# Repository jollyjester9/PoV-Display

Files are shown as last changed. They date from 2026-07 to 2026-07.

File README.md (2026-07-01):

<br/>
<div align="left">

<h2 align="left">Peristance of Vision Display</h2>
<p align="left">
ESP32 powered PoV Display

</p>
</div>

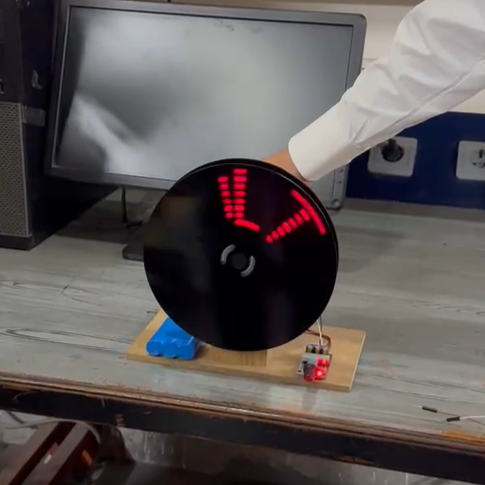
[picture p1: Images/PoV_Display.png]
PoV Display


## About The Project

This project aims to Create a rotating word display using an array of eight LEDs Powered by an ESP32 microcontroller.

## Components/ Parts List

### Off the shelf:
- ESP32 Dev Board
- RS-775 Motor
- PWM Dimmer
- 11.1 Volt Lithium Battery
- 4.8 Volt Lithium Battery
- M4*12 screws x 4
- M3*4 screws x 4
- SS41F Hall Effect Sensor
- 5mm LEDs (Red) x 8
- 330 ohm resistor x 8
- 10 kilo ohm resistor x 1

### Custom:
- Motor Mount
- Motor Adapter
- ESP Mount
- Rotating Disk
- Stationary Disk

## Built With

- [Arduino IDE](https://www.arduino.cc/en/software/)
- [Fusion](https://www.autodesk.com/products/fusion-360/overview)

## Hardware assembly

The assembly consists of two disks, one stationary and one rotating. Two Neodymium magnets are placed on the stationary disk, 144 degrees apart, which acts as the trigger angle and sets the output window size. The magnets are placed with opposite poles facing outward. A bipolar hall effect latch is used to detect the alternating magnetic field and enable/ disable the LED array as well as calculate disk RPM.

### Stationary Disk:

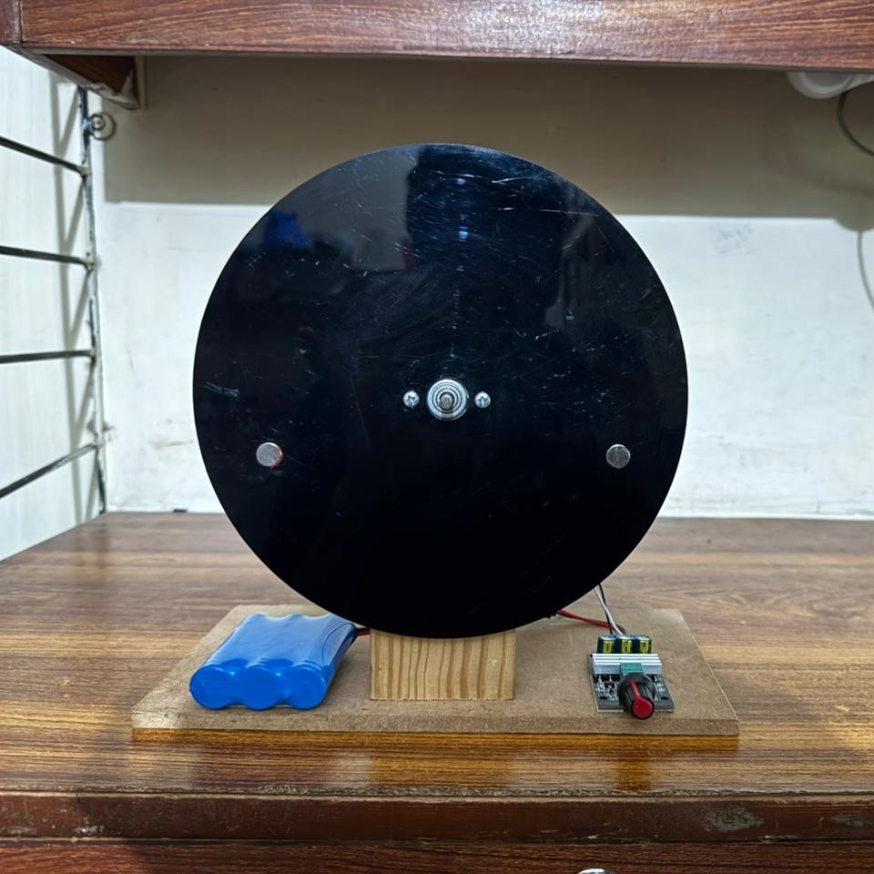
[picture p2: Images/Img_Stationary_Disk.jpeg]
Stationary_Disk


### Rotating Disk:

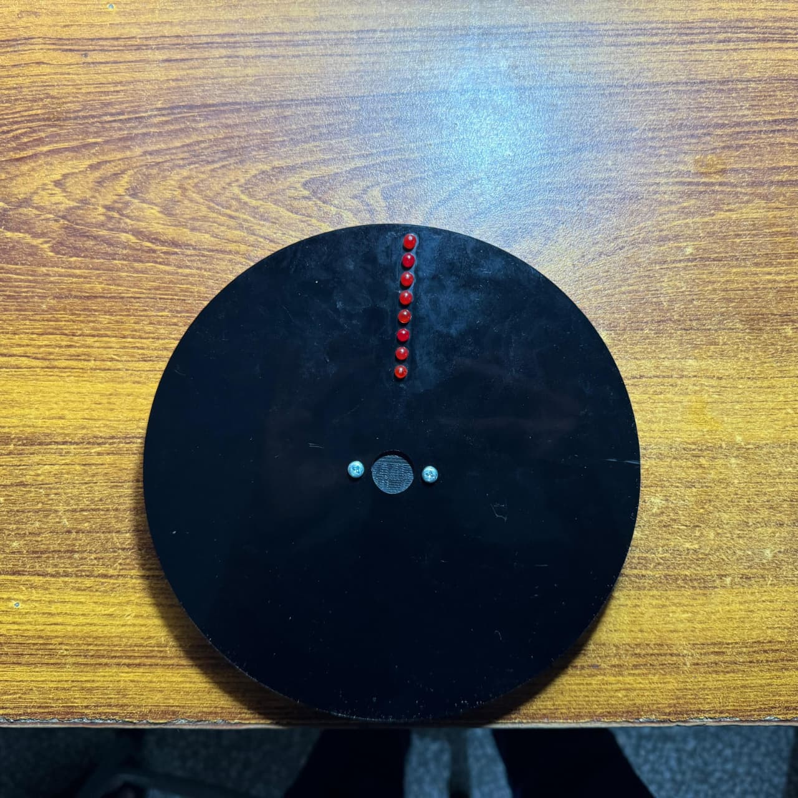
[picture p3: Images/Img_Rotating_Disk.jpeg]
Rotating_Disk


### Rotating Disk (Backside):

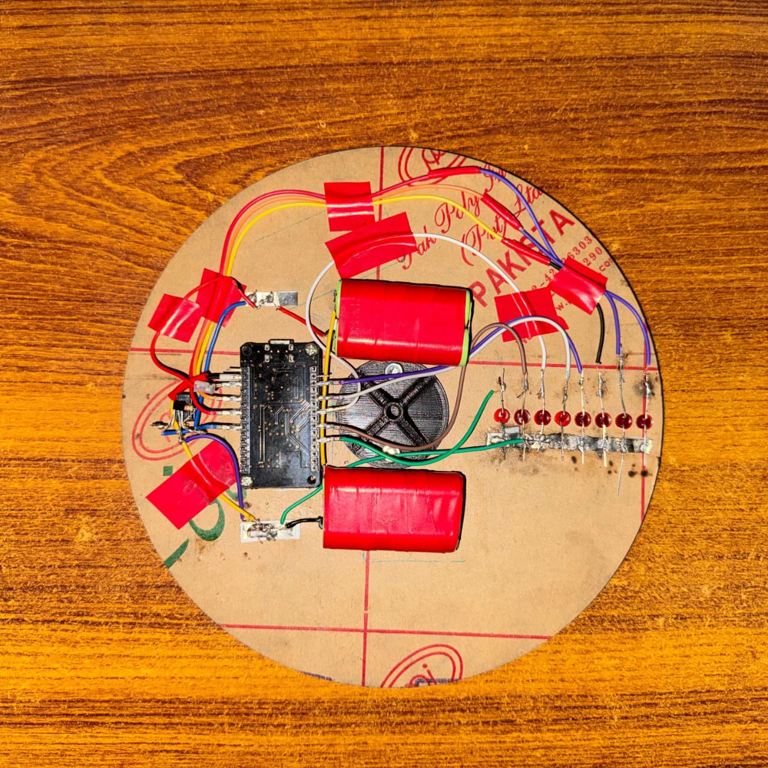
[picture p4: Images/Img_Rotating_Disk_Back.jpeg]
Rotating_Disk


The rotating disk is divided into 60 columns which gives, the number of columns available for display are:

$${144 \over 360} \times 60 = 24$$

The Rotating disk is spun using an RS-775 motor, a PWM dimmer is used to control motor RPM;
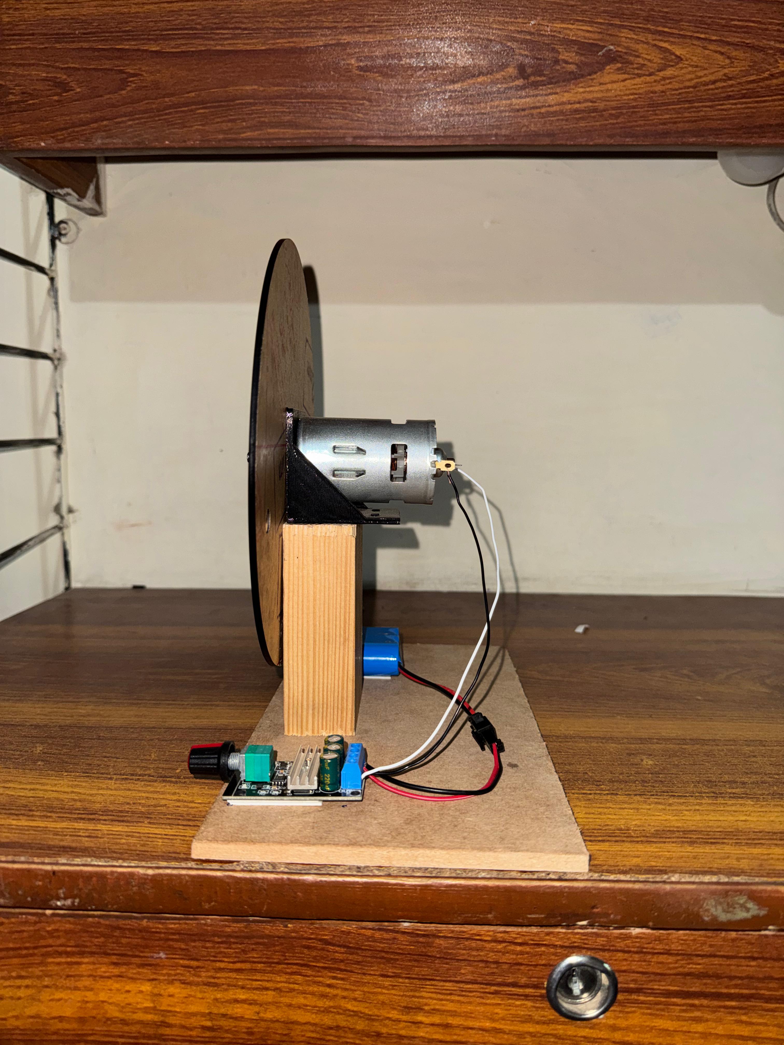
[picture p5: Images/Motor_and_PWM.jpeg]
Motor


## Code overview

To change display resolution, edit:
```sh
   #define NUM_COLS  23
   ```   
To change window size, edit (note: this will require changing magnet spacing on the stationary disk)
```sh
   #define ACTIVE_FRAC 0.4f
   ```

In [Encoding.xlsx](https://github.com/jollyjester9/PoV-Display/blob/main/Encoding.xlsx), each character takes 5 columns so by default, a four character expression is supported with 1 column acting as spacing between characters.

The characters are stored as hex values, for example, 'V' is stored as;
```sh
   const uint8_t CHAR_V[5] = {0x07, 0x38, 0xC0, 0x38, 0x07};
   ```

The code iterates through all 24 columns, updates the current columns and outputs the corresponding 8 bit value to the LEDs

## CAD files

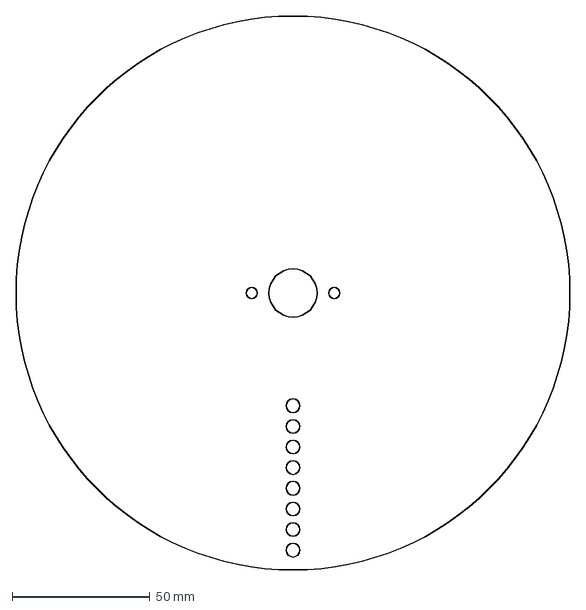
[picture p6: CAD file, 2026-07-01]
Parts/Rotating_Disk.dxf
201.4 x 201.4 mm

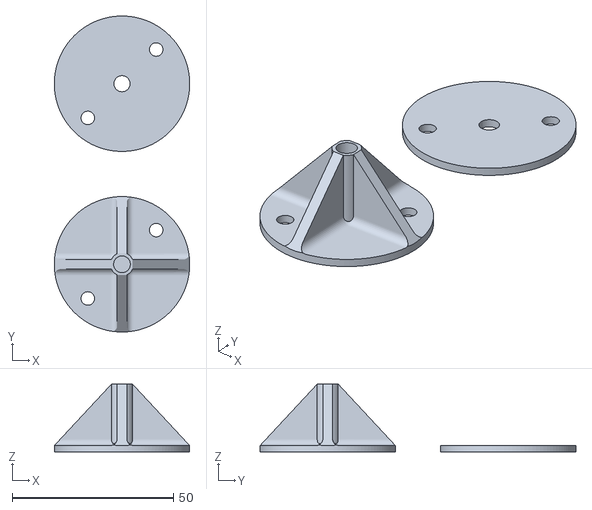
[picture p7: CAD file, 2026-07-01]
Parts/Motor_Adapter_v1.2.stl
42.0 x 98.0 x 21.0

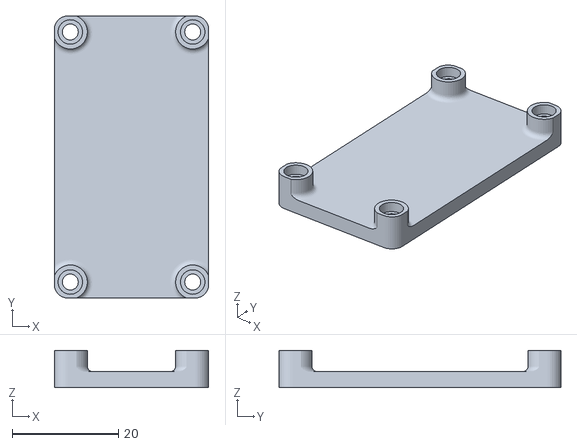
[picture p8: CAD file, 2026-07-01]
Parts/ESP_Mount.stl
29.0 x 53.0 x 7.00

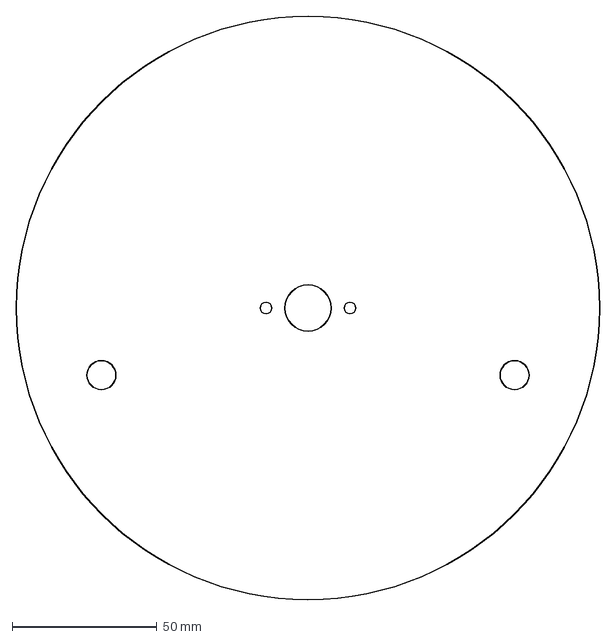
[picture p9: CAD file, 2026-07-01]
Parts/Stationary_Disk.dxf
201.4 x 201.4 mm

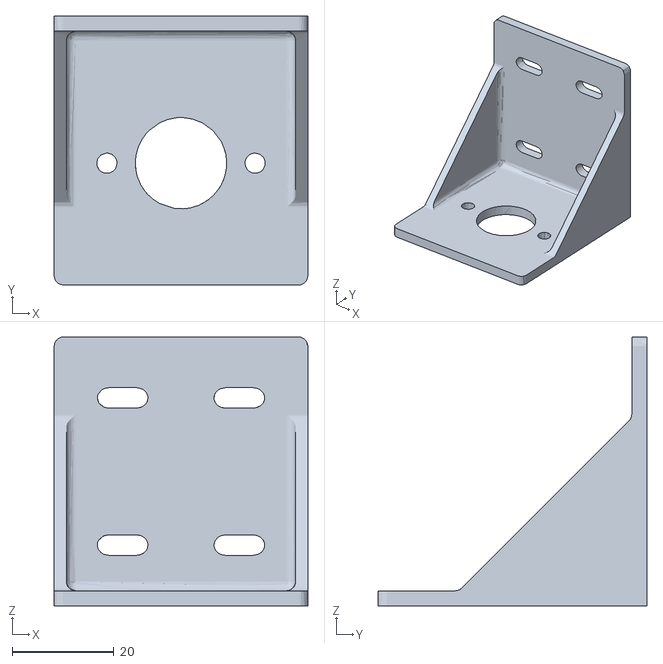
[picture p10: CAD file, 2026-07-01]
Parts/775_Motor_Mounting_Bracket_-_Reinforced_v1.1.stl
50.0 x 53.0 x 53.0

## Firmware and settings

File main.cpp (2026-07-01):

#define HALL_PIN     33
#define NUM_COLS     23
#define ACTIVE_FRAC  0.4f

const uint8_t LED_PINS[8] = {26, 14, 13, 15, 4, 17, 18, 21};

const uint8_t CHAR_V[5] = {0x07, 0x38, 0xC0, 0x38, 0x07};
const uint8_t CHAR_O[5] = {0x7E, 0x81, 0x81, 0x81, 0x7E};
const uint8_t CHAR_L[5] = {0xFF, 0x80, 0x80, 0x80, 0x80};
const uint8_t CHAR_T[5] = {0x01, 0x01, 0xFF, 0x01, 0x01};

uint8_t columnReg = 0x00;

volatile uint32_t lastRisingUs = 0;
volatile uint32_t revolutionUs = 0;
volatile bool     newPeriod    = false;

void IRAM_ATTR onHallRising() 
{
    uint32_t now = micros();
    if (lastRisingUs != 0) 
	{
        uint32_t period = now - lastRisingUs;
        if (period > 10000UL && period < 2000000UL) 
		{
            revolutionUs = period;
            newPeriod    = true;
        }
    }
    lastRisingUs = now;
}

inline uint8_t getColumn(uint8_t col) 
{
    if (col < 5)   return CHAR_V[col];
    if (col == 5)  return 0x00;
    if (col < 11)  return CHAR_O[col - 6];
    if (col == 11) return 0x00;
    if (col < 17)  return CHAR_L[col - 12];
    if (col == 17) return 0x00;
    return CHAR_T[col - 18];
}

inline void writeLEDs(uint8_t reg) 
{
    for (uint8_t bit = 0; bit < 8; bit++) 
	{
        digitalWrite(LED_PINS[bit], (reg >> bit) & 0x01);
    }
}

inline void ledsOff() 
{
    columnReg = 0x00;
    for (uint8_t i = 0; i < 8; i++) digitalWrite(LED_PINS[i], LOW);
}

void setup() {
    for (uint8_t i = 0; i < 8; i++) 
	{
        pinMode(LED_PINS[i], OUTPUT);
        digitalWrite(LED_PINS[i], LOW);
    }
    pinMode(HALL_PIN, INPUT);
    attachInterrupt(digitalPinToInterrupt(HALL_PIN), onHallRising, RISING);
    Serial.begin(115200);
    Serial.println("PoV display ready.");
}

void loop() 
{
    while (digitalRead(HALL_PIN) == LOW) { /* spin */ }

    uint32_t periodUs;
    portDISABLE_INTERRUPTS();
    periodUs = revolutionUs;
    portENABLE_INTERRUPTS();

    if (periodUs == 0) 
	{
        while (digitalRead(HALL_PIN) == HIGH) { /* spin */ }
        return;
    }

    uint32_t colDelayUs = (uint32_t)((float)periodUs * ACTIVE_FRAC / NUM_COLS);
    if (colDelayUs < 10) colDelayUs = 10;

    uint32_t windowStart = micros();

    for (uint8_t col = 0; col < NUM_COLS; col++) 
	{
        if (digitalRead(HALL_PIN) == LOW) break;

        columnReg = getColumn(col);
        writeLEDs(columnReg);

        uint32_t slotEnd = windowStart + (uint32_t)((col + 1) * colDelayUs);
        while ((int32_t)(micros() - slotEnd) < 0) { /* spin */ }
    }

    ledsOff();
    while (digitalRead(HALL_PIN) == HIGH) { /* spin */ }

    if (newPeriod) 
	{
        newPeriod = false;
        float rpm = 60000000.0f / (float)periodUs;
    }
}
